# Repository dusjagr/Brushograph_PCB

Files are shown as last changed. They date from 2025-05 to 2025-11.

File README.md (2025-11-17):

# Brushograph PCB

This repository contains the KiCad PCB design files for the Brushograph (miniPenzlograf) project, a pen-plotting device designed for creating artistic drawings and patterns.

**A manufacturing-ready PCB-design to run FluidNC on ESP32 including ULN2003 drivers for 3 uni-polar stepper motors (28byj-48)**

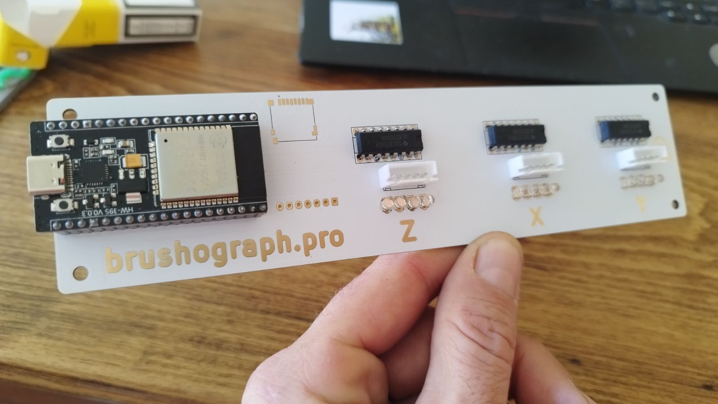
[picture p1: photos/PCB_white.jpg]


**A DIY etchable PCB-design to run FluidNC on ESP32 including ULN2003 drivers for 3 uni-polar stepper motors (28byj-48)**

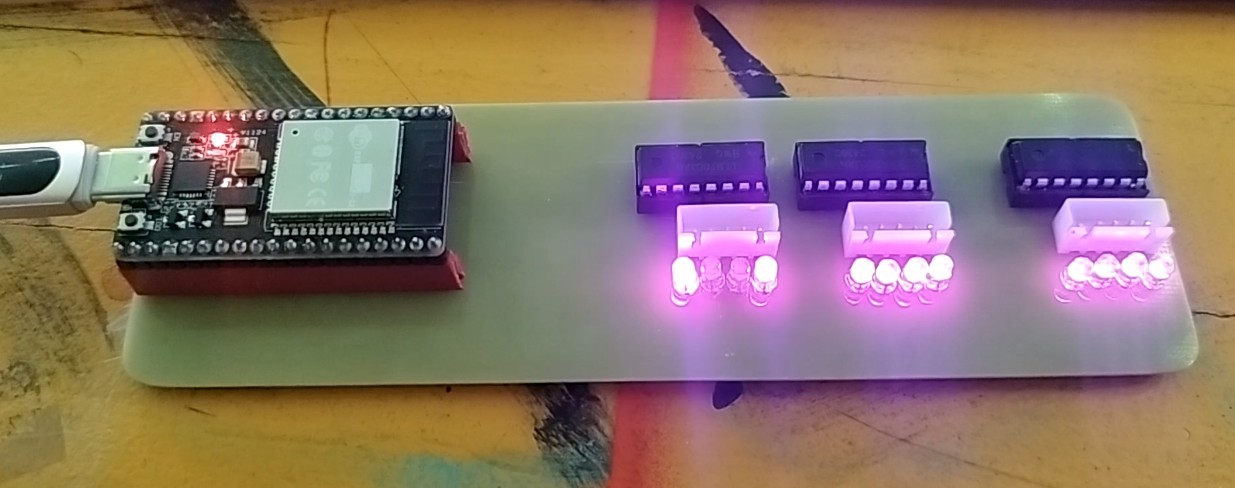
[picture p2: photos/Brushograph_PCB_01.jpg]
Brushograph PCB


## About Brushograph

This PCB repository is part of the larger Brushograph project, which explores "Ways of painting with a mechatronic brush" - an intersection between classical artistic techniques and modern technology.

**Main Documentation:**
- [Brushograph Wiki](https://wiki.sgmk-ssam.ch/wiki/Brushograph) - Complete project documentation

## Project Structure

- `Brusograf_PCB/` - Main KiCad project directory
  - `.kicad_pcb` files - PCB layout files
  - `.kicad_sch` - Schematic files
  - `.kicad_pro` - Project files
  - `MASK/` - Contains mask files in SVG and PDF format for PCB silkscreen
- `Brushograf_PCB-china/` - Latest KiCad project prepared for fabrication
  - `Gerber_Brusograf/` - Generated Gerber set for PCB manufacturing
  - `Gerber_Brusograf_black.zip` - Zipped Gerbers ready to upload to your PCB manufacturer
- `FluidNC_config/` - Configuration for FluidNC firmware
- `photos/` - Project photos and documentation images

## Features

- Custom PCB design for the Brushograph device
- ESP32-based control board with FluidNC firmware support
- Integrated ULN2003 drivers for 3 uni-polar stepper motors (28byj-48)
- DIY etchable single-layer design for easy home fabrication
- Rounded PCB version available
- Configuration files for FluidNC firmware (custom fork for support uni-polar steppers)

## Hardware Configuration

### ESP32 Pin Configuration

The Brushograph PCB uses the following ESP32 GPIO pins for controlling the stepper motors via ULN2003 drivers:

#### X-Axis Motor (Unipolar)
- Phase 0: GPIO 27
- Phase 1: GPIO 14
- Phase 2: GPIO 13
- Phase 3: GPIO 4

#### Y-Axis Motor (Unipolar)
- Phase 0: GPIO 16
- Phase 1: GPIO 17
- Phase 2: GPIO 21
- Phase 3: GPIO 22

#### Z-Axis Motor (Unipolar)
- Phase 0: GPIO 26
- Phase 1: GPIO 25
- Phase 2: GPIO 33
- Phase 3: GPIO 32

#### SD Card (SPI)
- MISO: GPIO 19
- MOSI: GPIO 23
- SCK: GPIO 18
- CS: GPIO 5

### Motor Configuration

The config.yaml file in the FluidNC_config directory contains all necessary settings for the stepper motors:

- X/Y Axis: 85 steps/mm, 1000mm/min max rate, 50mm/s² acceleration
- Z Axis: 78 steps/mm, 1000mm/min max rate, 30mm/s² acceleration

### 28BYJ-48 Stepper Motors

The PCB is designed specifically for the commonly available and inexpensive 28BYJ-48 unipolar stepper motors:
- 5V DC operation
- Gear reduction ratio of 1:64
- Step angle of 5.625° (64 steps per revolution)
- 4-phase operation via ULN2003 driver

## Getting Started

To view or modify the PCB design:
1. Install KiCad (version 6.0 or later recommended)
2. Open the `.kicad_pro` project file in the `Brusograf_PCB` directory
     - For the latest manufacturing-ready version, you can also open the project in `Brushograf_PCB-china/`

For complete setup instructions, including firmware and mechanical assembly, please refer to the [Brushograph Wiki](https://wiki.sgmk-ssam.ch/wiki/Brushograph).

## Manufacturing-ready files

- Latest Gerbers (ZIP, ready for fab): [`Brushograf_PCB-china/Gerber_Brusograf_black.zip`](Brushograf_PCB-china/Gerber_Brusograf_black.zip)
- Gerber folder (all layers and drill files): [`Brushograf_PCB-china/Gerber_Brusograf/`](Brushograf_PCB-china/Gerber_Brusograf/)

## Related Repositories

- [FluidNC for unipolar steppers](https://git.kompot.si/g1smo/FluidNC) - Forked and reworked version of FluidNC to support uni-polar steppers

## License

[Specify license here]

## Credits

Designed by dusjagr

The Brushograph project is based on Dominik Mahnič's "Brušografia" concept, bridging traditional painting and technology.

## Contact

[Your contact information here]

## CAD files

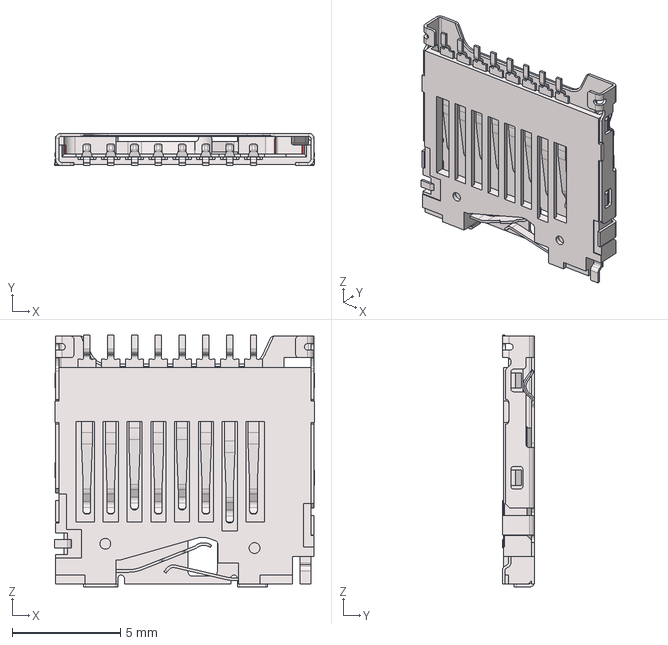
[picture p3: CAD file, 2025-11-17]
Brushograf_PCB-china/footprints/3d/SD_CARD_MICRO_AMPHENOL_1140084168.step
12.0 x 1.50 x 11.7 mm

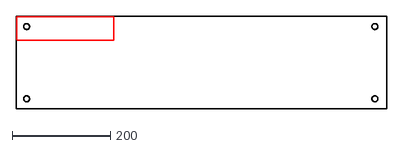
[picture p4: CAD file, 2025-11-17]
Brushograf_PCB-china/svg2shenzhen/brushograf_edgeCut.dxf
755.9 x 189.0

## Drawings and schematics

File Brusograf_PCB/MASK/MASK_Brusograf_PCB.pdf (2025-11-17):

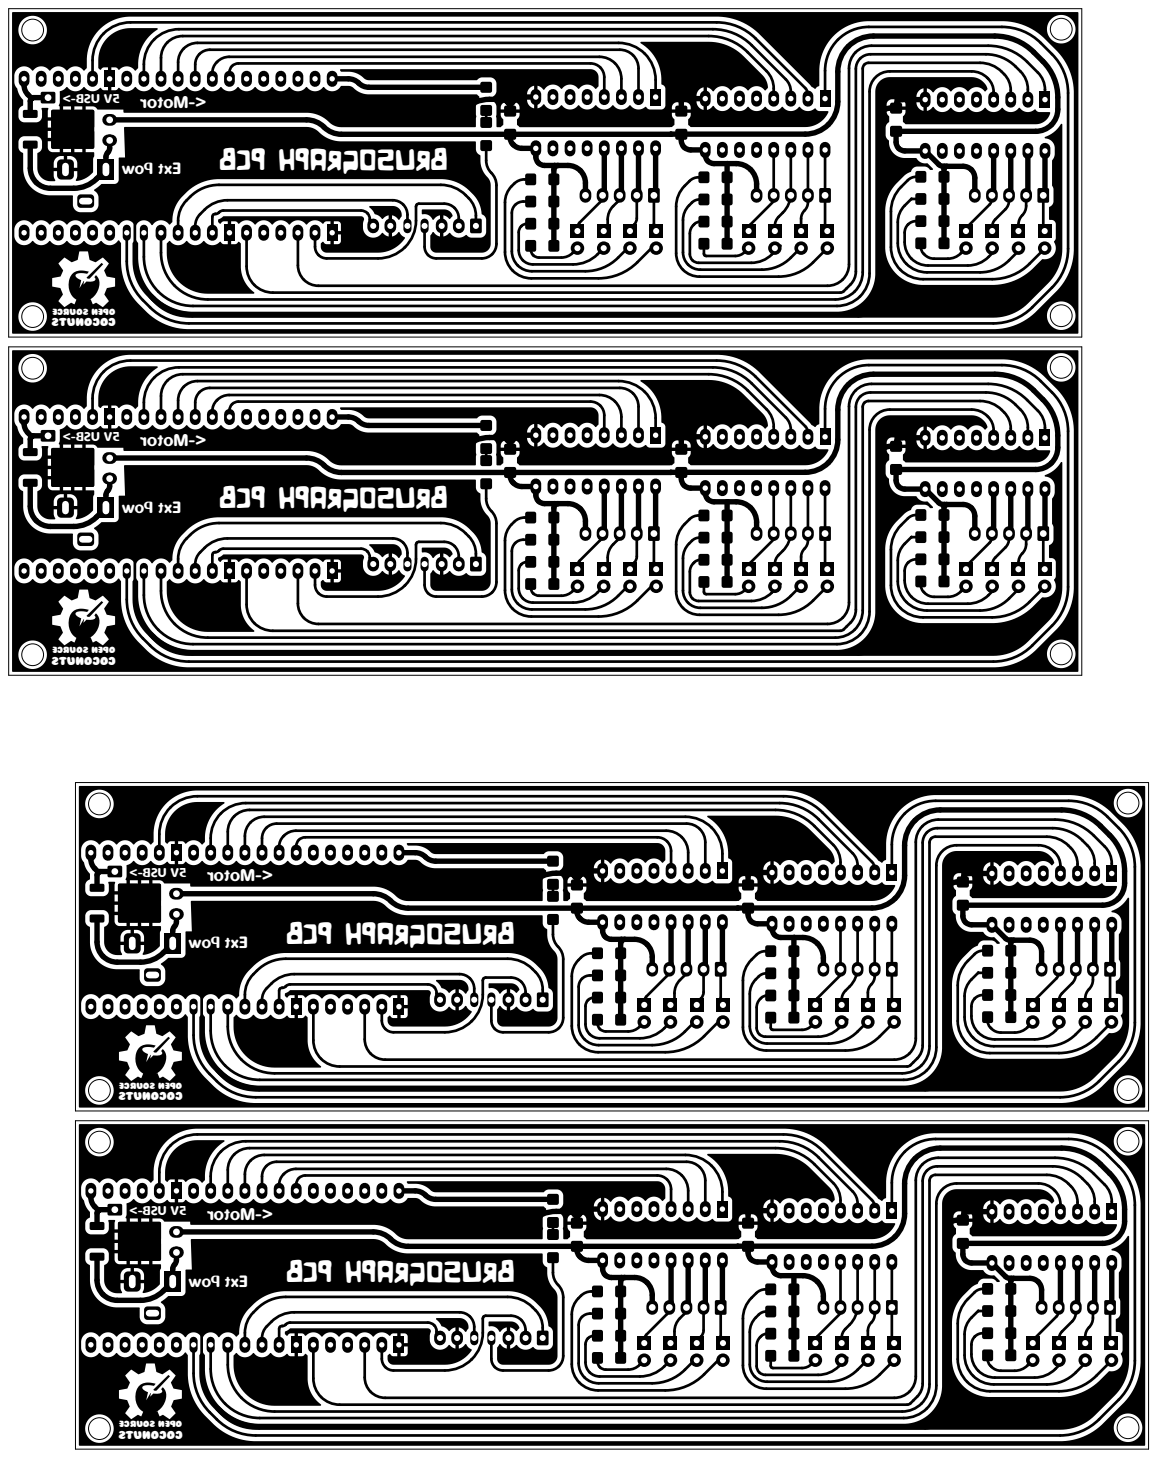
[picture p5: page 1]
<-Motor; Ext Pow; 5V USB->; Coconuts; Open Source; Brusograph PCB

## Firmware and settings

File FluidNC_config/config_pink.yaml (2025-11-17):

name: FluidNC ULN2003 Config
board: ESP32
stepping:
  engine: RMT
  idle_ms: 250
  dir_delay_us: 1
  pulse_us: 8
  disable_delay_us: 0
axes:
  shared_stepper_disable_pin: NO_PIN
  x:
    steps_per_mm: 93
    max_rate_mm_per_min: 1500
    acceleration_mm_per_sec2: 80
    max_travel_mm: 200
    motor0:
      unipolar:
        phase0_pin: gpio.27
        phase1_pin: gpio.14
        phase2_pin: gpio.13
        phase3_pin: gpio.4
      limit_neg_pin: NO_PIN
      limit_pos_pin: NO_PIN
      limit_all_pin: NO_PIN
  y:
    steps_per_mm: 93
    max_rate_mm_per_min: 1500
    acceleration_mm_per_sec2: 80
    max_travel_mm: 200
    motor0:
      unipolar:
        phase0_pin: gpio.22
        phase1_pin: gpio.21
        phase2_pin: gpio.17
        phase3_pin: gpio.16
      limit_neg_pin: NO_PIN
      limit_pos_pin: NO_PIN
      limit_all_pin: NO_PIN
  z:
    steps_per_mm: 108
    max_rate_mm_per_min: 1000
    acceleration_mm_per_sec2: 40
    max_travel_mm: 100
    motor0:
      unipolar:
        phase0_pin: gpio.32
        phase1_pin: gpio.33
        phase2_pin: gpio.25
        phase3_pin: gpio.26
      limit_neg_pin: NO_PIN
      limit_pos_pin: NO_PIN
      limit_all_pin: NO_PIN
macros:
  startup_line0: G53 Z10 & G53 Z0
  macro0: 
  macro1: 
  macro2: 
  after_reset:

spi:
  miso_pin: gpio.23
  mosi_pin: gpio.19
  sck_pin: gpio.18
sdcard:
  card_detect_pin: no_pin
  cs_pin: gpio.5

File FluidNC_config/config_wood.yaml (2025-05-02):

name: FluidNC ULN2003 Config
board: ESP32
stepping:
  engine: RMT
  idle_ms: 250
  dir_delay_us: 1
  pulse_us: 8
  disable_delay_us: 0
axes:
  shared_stepper_disable_pin: NO_PIN
  x:
    steps_per_mm: 85
    max_rate_mm_per_min: 1000
    acceleration_mm_per_sec2: 50
    max_travel_mm: 200
    motor0:
      unipolar:
        phase0_pin: gpio.27
        phase1_pin: gpio.14
        phase2_pin: gpio.13
        phase3_pin: gpio.4
      limit_neg_pin: NO_PIN
      limit_pos_pin: NO_PIN
      limit_all_pin: NO_PIN
  y:
    steps_per_mm: 85
    max_rate_mm_per_min: 1000
    acceleration_mm_per_sec2: 50
    max_travel_mm: 200
    motor0:
      unipolar:
        phase0_pin: gpio.22
        phase1_pin: gpio.21
        phase2_pin: gpio.17
        phase3_pin: gpio.16
      limit_neg_pin: NO_PIN
      limit_pos_pin: NO_PIN
      limit_all_pin: NO_PIN
  z:
    steps_per_mm: 78
    max_rate_mm_per_min: 300
    acceleration_mm_per_sec2: 30
    max_travel_mm: 100
    motor0:
      unipolar:
        phase0_pin: gpio.32
        phase1_pin: gpio.33
        phase2_pin: gpio.25
        phase3_pin: gpio.26
      limit_neg_pin: NO_PIN
      limit_pos_pin: NO_PIN
      limit_all_pin: NO_PIN
macros:
  startup_line0: 
  macro0: G0X30Y30F12000
  macro1: G0X-10Y-10F1200&G0 X-8 Y-8 F500&G10 P0 L20 X0&G10 P0 L20 Y0
  after_reset: G53 Z10 & G53 X140 Y140 Z15 & G53 X0 Y0 Z10 & G10 P0 L20 X0 Y0 Z10 & G1 Z15 F300 & G1 Z10 F300 & G0 X-10 Y-10 F1200 & G0 X-8 Y-8 F500 & G10 P0 L20 X0 Y0

spi:
  miso_pin: gpio.19
  mosi_pin: gpio.23
  sck_pin: gpio.18
sdcard:
  card_detect_pin: no_pin
  cs_pin: gpio.5

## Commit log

2025-05-01 Initial commit of miniPenzlograf KiCad project
    [Brusograf_PCB-rounded.kicad_pcb, Brusograf_PCB.kicad_pcb, Brusograf_PCB.kicad_sch]
2025-05-01 Reorganize folder structure and improve README
    [config.yaml]
2025-05-02 Add detailed hardware configuration to README
    [config_wood.yaml]
2025-11-17 fully manucturable PCB design and gerbers
    [Brushograf_PCB-china.kicad_pcb, Brushograf_PCB-china.kicad_sch, Brusograf_PCB-rounded.kicad_pcb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]
2025-11-17 modded readme with the PCB for manufacturing
